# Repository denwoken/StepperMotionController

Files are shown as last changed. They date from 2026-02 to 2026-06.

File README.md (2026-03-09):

# StepperMotionController
StepperMotionController is a full hardware + firmware + software stack for controlling multiple stepper motors over RS-485 (Modbus RTU). You configure the required motion parameters, set a target position, and the controller computes and executes the motion trajectory and speed profile based on current speed and acceleration limits.

This repo contains the STM32G0 firmware, the PCB design, and a Python SDK.

Planned: feedback sensor support for detecting missed steps, plus richer driver control via a shared UART connected to all TMC2209 drivers.

**Repository Layout**
- `firmware/` STM32G071 firmware (FreeRTOS) that exposes a Modbus RTU register map for motor control.
- `controller_sdk/python/` Python SDK built on `pyserial` with a high-level API and examples.
- `Altium/` PCB/schematic sources for the controller hardware.
- `DeviceRegisters.xlsx` Source-of-truth register map.
- `mbpool device registers.mbw` Modbus Poll workspace for register testing.
- `firmware/Core/DeviceRegisters/` Generated C register map used by firmware.
- `firmware/scripts/` Tools to generate register map files from the Excel table.
- `LegacyDeviceRegisters/` Older register map versions and outputs.
- `firmware/Doc/` MCU datasheet, reference manual, and FreeRTOS docs.
- `firmware.code-workspace` VS Code workspace for firmware development.
- `AltiumProjectGroup.DsnWrk` Altium project group workspace file.

**Quick Start (Python)**
1. Install dependencies:
   `python -m pip install -r controller_sdk/python/requirements.txt`
2. Run the example (edit port and baudrate as needed):
   `python controller_sdk/python/examples/basic_usage.py`

Minimal python usage:
```python
from stepper_controller import StepperController

with StepperController(port="COM9", baudrate=256000, slave_id=1) as ctrl:
    print(ctrl.read_device_id())
    motor = ctrl.motor(0)
    motor.enable(True)
    motor.set_max_velocity(128000)
    motor.move_relative(64000)
```

**Firmware Build**
1. Open `firmware.code-workspace` in VScode press F5 to build and start debugging session.

Notes:
- Modbus RTU is configured on `USART1` with RS-485 DE; the default baudrate is `256000`.
- The firmware expects the register map generated into `firmware/Core/DeviceRegisters/`.

**Register Map**
The register map starts in `DeviceRegisters.xlsx` and is used by both firmware and the Python SDK.

SDK compatibility:
- `controller_sdk/python/stepper_controller/device_registers.py` mirrors the firmware map.
- The SDK checks the map version on `open()` and raises `RegisterMapMismatchError` if it differs. You can disable this check with `StepperController(..., verify_map_version=False)`.

**Hardware**
Open the Altium project in `Altium/` to view schematics and PCB layout.

**License**
MIT. See `LICENSE`.

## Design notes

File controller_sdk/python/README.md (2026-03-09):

**Overview**
This folder contains a small Python module that talks to the controller over Modbus RTU and exposes high-level methods for every register defined in `Core/DeviceRegisters`.

**Install**
1. Optional: create and activate a virtual environment.
2. Install dependencies with `python -m pip install -r requirements.txt`.

**Example**
From this folder: `python examples\basic_usage.py` (update port and baudrate).
From repo root: `python controller_sdk\python\examples\basic_usage.py`.

**Notes**
- Motor index is 0..motor_count-1 by default. Use `motor(one_based=True)` if you prefer 1..N.
- 32-bit registers use low-word then high-word order (matches firmware mapping).
- The client accepts absolute Modbus addresses (40000+) and 0-based indices.
- On `open()` the client checks register map version and raises `RegisterMapMismatchError` on mismatch. You can disable via `StepperController(..., verify_map_version=False)`.

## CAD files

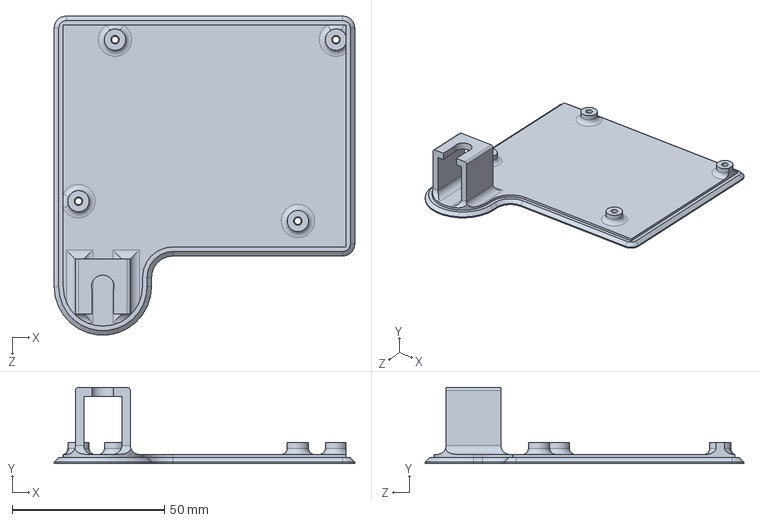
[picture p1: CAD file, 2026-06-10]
SolidWorks/PCB mounting plate.SLDPRT
98.7 x 25.0 x 104.7 mm

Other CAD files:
SolidWorks/PCB mounting plate.STL

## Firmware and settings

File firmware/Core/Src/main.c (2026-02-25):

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
/* Includes ------------------------------------------------------------------*/
#include "main.h"
#include "cmsis_os.h"
#include "crc.h"
#include "dma.h"
#include "i2c.h"
#include "spi.h"
#include "tim.h"
#include "usart.h"
#include "gpio.h"

/* USER CODE BEGIN Includes */
#include "FreeRTOS.h"
#include "semphr.h"
#include <stdio.h>

/* USER CODE END Includes */


void SystemClock_Config(void);
void MX_FREERTOS_Init(void);
/* USER CODE BEGIN PFP */


/*
static SemaphoreHandle_t ITM_mutex;
int _write(int file, char *ptr, int len)
{
  if(ITM_mutex == NULL)
    ITM_mutex = xSemaphoreCreateMutex();

    if (xSemaphoreTake(ITM_mutex, portMAX_DELAY) == pdTRUE)
    {
        for (int i = 0; i < len; i++){
            // Ждём пока USART готов к отправке
            while(!LL_USART_IsActiveFlag_TXE(USART1));
            LL_USART_TransmitData8(USART1, ptr[i]);
        }
        xSemaphoreGive(ITM_mutex);
    }
    return len;
}
*/
/* USER CODE END PFP */

/**
  * @brief  The application entry point.
  * @retval int
  */
int main(void)
{

  /* MCU Configuration--------------------------------------------------------*/

  /* Reset of all peripherals, Initializes the Flash interface and the Systick. */
  HAL_Init();

  /* Configure the system clock */
  SystemClock_Config();

  /* Initialize all configured peripherals */
  MX_GPIO_Init();
  MX_DMA_Init();
  MX_TIM6_Init();
  MX_TIM15_Init();
  MX_USART1_UART_Init();
  MX_TIM7_Init();
  MX_I2C1_Init();
  MX_I2C2_Init();
  MX_SPI1_Init();
  MX_TIM1_Init();
  MX_TIM2_Init();
  MX_TIM3_Init();
  MX_TIM16_Init();
  MX_TIM17_Init();
  MX_CRC_Init();
  /* Call init function for freertos objects (in cmsis_os2.c) */
  MX_FREERTOS_Init();

  /* Start scheduler */
  osKernelStart();

  /* We should never get here as control is now taken by the scheduler */

  /* Infinite loop */
  /* USER CODE BEGIN WHILE */
  while (1)
  {
    /* USER CODE END WHILE */

    /* USER CODE BEGIN 3 */
  }
  /* USER CODE END 3 */
}

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


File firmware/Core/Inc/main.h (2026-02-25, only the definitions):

#define PC11_Pin LL_GPIO_PIN_11
#define PC11_GPIO_Port GPIOC
#define PC12_Pin LL_GPIO_PIN_12
#define PC12_GPIO_Port GPIOC
#define PC13_Pin LL_GPIO_PIN_13
#define PC13_GPIO_Port GPIOC
#define PC14_Pin LL_GPIO_PIN_14
#define PC14_GPIO_Port GPIOC
#define PC15_Pin LL_GPIO_PIN_15
#define PC15_GPIO_Port GPIOC
#define DRV1_DIR_Pin LL_GPIO_PIN_0
#define DRV1_DIR_GPIO_Port GPIOC
#define DRV1_NEN_Pin LL_GPIO_PIN_2
#define DRV1_NEN_GPIO_Port GPIOC
#define DRV5_NEN_Pin LL_GPIO_PIN_3
#define DRV5_NEN_GPIO_Port GPIOC
#define DRV5_DIR_Pin LL_GPIO_PIN_1
#define DRV5_DIR_GPIO_Port GPIOA
#define DRV2_DIR_Pin LL_GPIO_PIN_5
#define DRV2_DIR_GPIO_Port GPIOA
#define DRV2_NEN_Pin LL_GPIO_PIN_7
#define DRV2_NEN_GPIO_Port GPIOA
#define DRV4_NEN_Pin LL_GPIO_PIN_15
#define DRV4_NEN_GPIO_Port GPIOB
#define DRV4_DIR_Pin LL_GPIO_PIN_9
#define DRV4_DIR_GPIO_Port GPIOA
#define ENC_BTN_Pin LL_GPIO_PIN_8
#define ENC_BTN_GPIO_Port GPIOD
#define DRV3_NEN_Pin LL_GPIO_PIN_0
#define DRV3_NEN_GPIO_Port GPIOD
#define DRV3_DIR_Pin LL_GPIO_PIN_2
#define DRV3_DIR_GPIO_Port GPIOD

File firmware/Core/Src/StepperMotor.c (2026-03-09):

#include "StepperMotor.h"
#include <assert.h>
#include <memory.h>
#include "config.h"


//declarations functions
static void StepperMotor_update(StepperMotor* self);
static void StepperMotor_init(StepperMotor* self, TIM_TypeDef *timer, GPIO_TypeDef *dir_port, uint16_t dir_pin,
	GPIO_TypeDef *en_port, uint16_t en_pin);
static void StepperMotor_setEnable(StepperMotor* self, bool enable);
static void StepperMotor_restartMotorTimer(StepperMotor* self);

static void StepperMotor_apply_control(StepperMotor* m, uint16_t value);
static void StepperMotor_apply_mode(StepperMotor* m, uint16_t value);
static void StepperMotor_apply_target_pos(StepperMotor* m, int32_t target);
static void StepperMotor_apply_move_rel(StepperMotor* m, int32_t move);



// link methods to class
static void StepperMotor_setAllmethods(StepperMotor* self){
	assert(self);
	self->update = StepperMotor_update;
	self->init = StepperMotor_init;
	self->setEnable = StepperMotor_setEnable;
	self->restartMotorTimer = StepperMotor_restartMotorTimer;

	self->apply_control = StepperMotor_apply_control;
	self->apply_mode = StepperMotor_apply_mode;
	self->apply_target_pos = StepperMotor_apply_target_pos;
	self->apply_move_rel = StepperMotor_apply_move_rel;

}


static inline int32_t _abs(int32_t x){ return x < 0 ? -x : x; }
static inline int32_t _min(int32_t a, int32_t b){ return a < b ? a : b; }
static inline int32_t _max(int32_t a, int32_t b){ return a > b ? a : b; }

const int s_max_velocity = 256000;


static void StepperMotor_apply_control(StepperMotor* m, uint16_t value)
{
	StepperMotorParameters* p = &m->parameters;
	
	// TODO: implement full control behavior (enable/disable, etc.)
	p->control.raw = value;

	m->setEnable(m, (bool)(value & MOTOR_CONTROL_EN_MASK));

	// Simple sketch: mirror enable bit into status and stop on disable.
	if ((value & MOTOR_CONTROL_EN_MASK)) {
		
		// p->remaining_steps = 0;
		// p->current_velocity = 0;
		// p->current_acceleration = 0;
		// p->move_pos_rel = 0;
		// p->target_pos = p->move_total_steps;
		// p->status.bits.running = 0u;
	}
	//p->status.bits.enabled = (value & MOTOR_CONTROL_EN_MASK) ? 1u : 0u;
}

static void StepperMotor_apply_mode(StepperMotor* m, uint16_t value)
{
	StepperMotorParameters* p = &m->parameters;
	// TODO: define mode semantics (position/velocity/step, etc.)
	p->mode = value;
}


#if defined(REG_ID_CMD)
static void StepperMotor_apply_cmd(StepperMotor* m, uint16_t value)
{
	const StepperMotorParameters* p = &m->parameters;
	// Write-only command register sketch.
	// TODO: replace with real command decoding.
	p->cmd = value;
	if (value & 0x0001u) {
		// CMD bit0: stop motion (placeholder action)
		p->remaining_steps = 0;
		p->current_velocity = 0;
		p->current_acceleration = 0;
		p->move_pos_rel = 0;
		p->target_pos = p->move_total_steps;
		p->status.bits.running = 0u;
	}
}
#endif

static void StepperMotor_apply_target_pos(StepperMotor* m, int32_t target)
{
	StepperMotorParameters* p = &m->parameters;
	p->target_pos = target;
	p->remaining_steps = p->target_pos - p->move_total_steps;
}

static void StepperMotor_apply_move_rel(StepperMotor* m, int32_t move)
{
	StepperMotorParameters* p = &m->parameters;
	p->remaining_steps += move;
	p->target_pos = p->move_total_steps + p->remaining_steps;
}








// methods
static void StepperMotor_update(StepperMotor* m){
	StepperMotorParameters* p = &m->parameters;
	//portENTER_CRITICAL();

	int8_t direction = (p->remaining_steps > 0) ? (1) : (-1);


	// Расчет дистанции торможения (правильная формула)
	// s = v² / (2 * a)
	int64_t brake_distance = 0;
	if (p->max_acceleration > 0) {
		brake_distance = ((int64_t)p->current_velocity * (int64_t)p->current_velocity);
		brake_distance /= (2 * p->max_acceleration);
	} else 
		brake_distance = INT64_MAX;
	int32_t abs_remaining = _abs(p->remaining_steps);

	

	
	//p->current_acceleration
	// ускорение за тик + аккумулируем значение если дробное
	int32_t total_acc = p->max_acceleration + m->accelerationAccumulated; 
	int32_t accel_per_tick =  total_acc / 1000;
	int32_t accel_sign = 0;
	m->accelerationAccumulated = total_acc % 1000;


	// Управление скоростью по трапециевидному профилю
	if ( abs_remaining <= brake_distance )
	{ // шагов нужно выполнить меньше чем нужно для тормаения
		//  ==> тормозим
		p->current_velocity = _max(0, p->current_velocity - accel_per_tick);
		accel_sign = -1;
	}
	else if (p->current_velocity < p->max_velocity ){
		// или если это не максимальная скорость  ==> ускоряемся
		p->current_velocity = _min(p->max_velocity, p->current_velocity + accel_per_tick);
		accel_sign = 1;
	}
	else if (p->current_velocity > p->max_velocity)
	{ // если vmax изменили в меньшую сторону ==> тормозим
		p->current_velocity = _max(p->max_velocity, p->current_velocity - accel_per_tick);
		accel_sign = -1;
	}


	// шаги/тик + аккумулируем значение если дробное
	p->current_acceleration = accel_sign * (int32_t)p->max_acceleration;

	int32_t total_vel = p->current_velocity + m->velocityAccumulated;
	int32_t vel_per_tick = total_vel / 1000;
	m->velocityAccumulated = total_vel % 1000;


	if (vel_per_tick != 0)
	{

		// НЕ допускать перепрыгивания через ноль:
		int32_t steps_to_move = vel_per_tick;
    if (steps_to_move > abs_remaining) steps_to_move = abs_remaining;

		if(steps_to_move > 256) steps_to_move = 256;

		//выбор направления двиения
		if(direction == 1){ 
			LL_GPIO_SetOutputPin(m->dir_port, m->dir_pin);
			p->remaining_steps -= steps_to_move;
			p->move_total_steps += steps_to_move;
		} else {
			LL_GPIO_ResetOutputPin(m->dir_port, m->dir_pin);
			p->remaining_steps += steps_to_move;
			p->move_total_steps -= steps_to_move;
		}
		if(p->remaining_steps == 0 ){
			//LL_GPIO_ResetOutputPin(m->dir_port, m->dir_pin);// дебаг
			p->current_velocity = 0;
			p->current_acceleration = 0;
			m->velocityAccumulated = 0;
			m->accelerationAccumulated = 0;
		}


		//LL_TIM_DisableCounter(m->timer);
		static const uint32_t timer_clk = 64000; // кГц
		LL_TIM_SetPrescaler(m->timer, ( timer_clk/(steps_to_move*2) ) );//- 1
    LL_TIM_SetRepetitionCounter(m->timer, steps_to_move - 1);//
		
		//LL_TIM_GenerateEvent_UPDATE(m->timer);
		//LL_TIM_EnableCounter(m->timer);
		m->pendingTimerRestart = true;

	} else m->pendingTimerRestart = false;

	if (vel_per_tick == 0 && p->remaining_steps == 0) {
		p->current_velocity = 0;
		p->current_acceleration = 0;
		m->velocityAccumulated = 0;
		m->accelerationAccumulated = 0;
	}

	p->target_pos = p->move_total_steps + p->remaining_steps;
	const uint16_t is_running = (p->remaining_steps != 0) ? 1u : 0u;
	p->status.bits.running = is_running;
	p->status.bits.enabled = is_running;

	//portEXIT_CRITICAL();
}


static void StepperMotor_setEnable(StepperMotor* self, bool enable){
	assert(self);
	assert(self->en_port);
	assert(self->en_pin != 0u);

	if(enable){
		// NEN is active-low: 0 = enabled, 1 = disabled.
		LL_GPIO_ResetOutputPin(self->en_port, self->en_pin);
	} else {
		LL_GPIO_SetOutputPin(self->en_port, self->en_pin);
	}
}
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

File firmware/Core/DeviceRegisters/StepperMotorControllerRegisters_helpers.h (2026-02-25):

#pragma once
#include "StepperMotorControllerRegisters_map.h"

// FW_VERSION helpers: high byte = register map version, low byte = firmware version (major*10+minor).
#define REG_FW_VERSION_PACK(map_ver, fw_ver) \
	((uint16_t)((((uint16_t)(map_ver) & 0xFFu) << 8) | ((uint16_t)(fw_ver) & 0xFFu)))
#define REG_FW_VERSION_MAP(ver_u16) ((uint8_t)(((uint16_t)(ver_u16) >> 8) & 0xFFu))
#define REG_FW_VERSION_SW(ver_u16)  ((uint8_t)((uint16_t)(ver_u16) & 0xFFu))
#define REG_FW_VERSION_MAJOR(ver_u16) ((uint8_t)(REG_FW_VERSION_SW(ver_u16) / 10u))
#define REG_FW_VERSION_MINOR(ver_u16) ((uint8_t)(REG_FW_VERSION_SW(ver_u16) % 10u))

// Helper macros for register addresses/sizes.
// - REG_SIZE_* is in 16-bit Modbus words (1 for 16-bit, 2 for 32-bit).
// - Motors in helper macros REG_Mx_* are 1-based in the name, but internally use 0-based indexing.

#define REG_BASE_DEVICE_ID ((uint16_t)40000)
#define REG_SIZE_DEVICE_ID ((uint8_t)1)
#define REG_PER_MOTOR_DEVICE_ID ((uint8_t)0)
#define REG_BASE_FW_VERSION ((uint16_t)40001)
#define REG_SIZE_FW_VERSION ((uint8_t)1)
#define REG_PER_MOTOR_FW_VERSION ((uint8_t)0)
#define REG_BASE_MOTOR_COUNT ((uint16_t)40002)
#define REG_SIZE_MOTOR_COUNT ((uint8_t)1)
#define REG_PER_MOTOR_MOTOR_COUNT ((uint8_t)0)
#define REG_BASE_CONTROL ((uint16_t)40008)
#define REG_SIZE_CONTROL ((uint8_t)1)
#define REG_PER_MOTOR_CONTROL ((uint8_t)1)
#define REG_BASE_STATUS ((uint16_t)40013)
#define REG_SIZE_STATUS ((uint8_t)1)
#define REG_PER_MOTOR_STATUS ((uint8_t)1)
#define REG_BASE_ERROR_CODE ((uint16_t)40018)
#define REG_SIZE_ERROR_CODE ((uint8_t)1)
#define REG_PER_MOTOR_ERROR_CODE ((uint8_t)1)
#define REG_BASE_MODE ((uint16_t)40023)
#define REG_SIZE_MODE ((uint8_t)1)
#define REG_PER_MOTOR_MODE ((uint8_t)1)
#define REG_BASE_CURRENT_POS_32 ((uint16_t)40032)
#define REG_SIZE_CURRENT_POS_32 ((uint8_t)2)
#define REG_PER_MOTOR_CURRENT_POS_32 ((uint8_t)1)
#define REG_BASE_CURRENT_VELOCITY_32 ((uint16_t)40042)
#define REG_SIZE_CURRENT_VELOCITY_32 ((uint8_t)2)
#define REG_PER_MOTOR_CURRENT_VELOCITY_32 ((uint8_t)1)
#define REG_BASE_CURRENT_ACCEL_32 ((uint16_t)40052)
#define REG_SIZE_CURRENT_ACCEL_32 ((uint8_t)2)
#define REG_PER_MOTOR_CURRENT_ACCEL_32 ((uint8_t)1)
#define REG_BASE_TARGET_POS_32 ((uint16_t)40062)
#define REG_SIZE_TARGET_POS_32 ((uint8_t)2)
#define REG_PER_MOTOR_TARGET_POS_32 ((uint8_t)1)
#define REG_BASE_MOVE_POS_REL_32 ((uint16_t)40072)
#define REG_SIZE_MOVE_POS_REL_32 ((uint8_t)2)
#define REG_PER_MOTOR_MOVE_POS_REL_32 ((uint8_t)1)
#define REG_BASE_MAX_VELOCITY_32 ((uint16_t)40082)
#define REG_SIZE_MAX_VELOCITY_32 ((uint8_t)2)
#define REG_PER_MOTOR_MAX_VELOCITY_32 ((uint8_t)1)
#define REG_BASE_MAX_ACCEL_32 ((uint16_t)40092)
#define REG_SIZE_MAX_ACCEL_32 ((uint8_t)2)
#define REG_PER_MOTOR_MAX_ACCEL_32 ((uint8_t)1)

#define REG_M1_CONTROL_ADDR (uint16_t)(REG_BASE_CONTROL + (uint16_t)(0) * (uint16_t)REG_SIZE_CONTROL)
#define REG_M1_CONTROL_OFFSET (uint16_t)((uint16_t)(0) * (uint16_t)REG_SIZE_CONTROL)
#define REG_M2_CONTROL_ADDR (uint16_t)(REG_BASE_CONTROL + (uint16_t)(1) * (uint16_t)REG_SIZE_CONTROL)
#define REG_M2_CONTROL_OFFSET (uint16_t)((uint16_t)(1) * (uint16_t)REG_SIZE_CONTROL)
#define REG_M3_CONTROL_ADDR (uint16_t)(REG_BASE_CONTROL + (uint16_t)(2) * (uint16_t)REG_SIZE_CONTROL)
#define REG_M3_CONTROL_OFFSET (uint16_t)((uint16_t)(2) * (uint16_t)REG_SIZE_CONTROL)
#define REG_M4_CONTROL_ADDR (uint16_t)(REG_BASE_CONTROL + (uint16_t)(3) * (uint16_t)REG_SIZE_CONTROL)
#define REG_M4_CONTROL_OFFSET (uint16_t)((uint16_t)(3) * (uint16_t)REG_SIZE_CONTROL)
#define REG_M5_CONTROL_ADDR (uint16_t)(REG_BASE_CONTROL + (uint16_t)(4) * (uint16_t)REG_SIZE_CONTROL)
#define REG_M5_CONTROL_OFFSET (uint16_t)((uint16_t)(4) * (uint16_t)REG_SIZE_CONTROL)

#define REG_M1_STATUS_ADDR (uint16_t)(REG_BASE_STATUS + (uint16_t)(0) * (uint16_t)REG_SIZE_STATUS)
#define REG_M1_STATUS_OFFSET (uint16_t)((uint16_t)(0) * (uint16_t)REG_SIZE_STATUS)
#define REG_M2_STATUS_ADDR (uint16_t)(REG_BASE_STATUS + (uint16_t)(1) * (uint16_t)REG_SIZE_STATUS)
#define REG_M2_STATUS_OFFSET (uint16_t)((uint16_t)(1) * (uint16_t)REG_SIZE_STATUS)
#define REG_M3_STATUS_ADDR (uint16_t)(REG_BASE_STATUS + (uint16_t)(2) * (uint16_t)REG_SIZE_STATUS)
#define REG_M3_STATUS_OFFSET (uint16_t)((uint16_t)(2) * (uint16_t)REG_SIZE_STATUS)
#define REG_M4_STATUS_ADDR (uint16_t)(REG_BASE_STATUS + (uint16_t)(3) * (uint16_t)REG_SIZE_STATUS)
#define REG_M4_STATUS_OFFSET (uint16_t)((uint16_t)(3) * (uint16_t)REG_SIZE_STATUS)
#define REG_M5_STATUS_ADDR (uint16_t)(REG_BASE_STATUS + (uint16_t)(4) * (uint16_t)REG_SIZE_STATUS)
#define REG_M5_STATUS_OFFSET (uint16_t)((uint16_t)(4) * (uint16_t)REG_SIZE_STATUS)

#define REG_M1_ERROR_CODE_ADDR (uint16_t)(REG_BASE_ERROR_CODE + (uint16_t)(0) * (uint16_t)REG_SIZE_ERROR_CODE)
#define REG_M1_ERROR_CODE_OFFSET (uint16_t)((uint16_t)(0) * (uint16_t)REG_SIZE_ERROR_CODE)
#define REG_M2_ERROR_CODE_ADDR (uint16_t)(REG_BASE_ERROR_CODE + (uint16_t)(1) * (uint16_t)REG_SIZE_ERROR_CODE)
#define REG_M2_ERROR_CODE_OFFSET (uint16_t)((uint16_t)(1) * (uint16_t)REG_SIZE_ERROR_CODE)
#define REG_M3_ERROR_CODE_ADDR (uint16_t)(REG_BASE_ERROR_CODE + (uint16_t)(2) * (uint16_t)REG_SIZE_ERROR_CODE)
#define REG_M3_ERROR_CODE_OFFSET (uint16_t)((uint16_t)(2) * (uint16_t)REG_SIZE_ERROR_CODE)
#define REG_M4_ERROR_CODE_ADDR (uint16_t)(REG_BASE_ERROR_CODE + (uint16_t)(3) * (uint16_t)REG_SIZE_ERROR_CODE)
#define REG_M4_ERROR_CODE_OFFSET (uint16_t)((uint16_t)(3) * (uint16_t)REG_SIZE_ERROR_CODE)
#define REG_M5_ERROR_CODE_ADDR (uint16_t)(REG_BASE_ERROR_CODE + (uint16_t)(4) * (uint16_t)REG_SIZE_ERROR_CODE)
#define REG_M5_ERROR_CODE_OFFSET (uint16_t)((uint16_t)(4) * (uint16_t)REG_SIZE_ERROR_CODE)

#define REG_M1_MODE_ADDR (uint16_t)(REG_BASE_MODE + (uint16_t)(0) * (uint16_t)REG_SIZE_MODE)
#define REG_M1_MODE_OFFSET (uint16_t)((uint16_t)(0) * (uint16_t)REG_SIZE_MODE)
#define REG_M2_MODE_ADDR (uint16_t)(REG_BASE_MODE + (uint16_t)(1) * (uint16_t)REG_SIZE_MODE)
#define REG_M2_MODE_OFFSET (uint16_t)((uint16_t)(1) * (uint16_t)REG_SIZE_MODE)
#define REG_M3_MODE_ADDR (uint16_t)(REG_BASE_MODE + (uint16_t)(2) * (uint16_t)REG_SIZE_MODE)
#define REG_M3_MODE_OFFSET (uint16_t)((uint16_t)(2) * (uint16_t)REG_SIZE_MODE)
#define REG_M4_MODE_ADDR (uint16_t)(REG_BASE_MODE + (uint16_t)(3) * (uint16_t)REG_SIZE_MODE)
#define REG_M4_MODE_OFFSET (uint16_t)((uint16_t)(3) * (uint16_t)REG_SIZE_MODE)
#define REG_M5_MODE_ADDR (uint16_t)(REG_BASE_MODE + (uint16_t)(4) * (uint16_t)REG_SIZE_MODE)
#define REG_M5_MODE_OFFSET (uint16_t)((uint16_t)(4) * (uint16_t)REG_SIZE_MODE)
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

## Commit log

2026-02-12 DEV: import altium files to project. Draft of the board for testing
    [Sheet.SchDoc, Sheet1.SchDoc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]
2026-02-14 DEV: developed registers for device
    [регистры modbus.xlsx]
2026-02-14 DEV: modify registers
    [modbus registers.xlsx, регистры modbus.xlsx]
2026-02-15 DEV: Implemented draft initialization for I2C, SPI, and TIM peripherals. Fixed timing parameters for RS-485 hardware control.
    [ModbusSlaveRTU.c, app_freertos.c, main.c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]
2026-02-16 DEV: added device registers for first motor fin "modbusPool" Application & creating workspace, also some fixes in code.
    [StepperMotionControl.ioc]
2026-02-16 DEV: add lfs filter
2026-02-16 DEV: moved motor parameters into StepperMotorParameters struct; fixed TIM15 config bug
    [StepperMotionControl.ioc, StepperMotor.c, app_freertos.c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]
2026-02-16 DEV: implemented simplified python script for generting DeviceRegisters.h/.c files from excel registers tabel
    [DeviceRegisters.xlsx, modbus registers.xlsx]
2026-02-22 tmp garbage
    [DeviceRegisters.xlsx]
2026-02-23 DEV: barely working modbus communication. in progress of removing 16bit reg copy
    [DeviceRegisters.xlsx]
2026-02-23 DEV: implementation of 32bit motion registers instead of 16bit. now you can move single StepperMotor via modbus registers
2026-02-23 DEV: fix some bugs. now its working
    [DeviceRegistersMapper.c, StepperMotionControl.ioc, StepperMotor.c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]
2026-02-25 DEV: fix some jitter bugs & sync motors. added crc base init.
    [StepperMotionControl.ioc, StepperMotor.c, StepperMotorController.c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]
2026-02-25 DEV: implemented macros hooks in StepperMotorController, automatic determination fw version from git tag
2026-02-25 DEV: renaming DeviceRegisters files
2026-03-09 something weird with altium schematic....
    [Sheet.SchDoc]
2026-06-09 rectified mistake in U1 commment; fixed mistake in sch and pcb
    [PCB1.PcbDoc, Sheet.SchDoc, Sheet1.SchDoc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]
2026-06-09 add PCB mounting plate model
    [PCB mounting plate.SLDPRT, PCB mounting plate.STL]
2026-06-10 Add PCB and assembly Draftsman documents and also GOST BOM
    [Bill of Materials-StepperMotionController.xls, PCB mounting plate.SLDPRT, PCB mounting plate.STL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]
2026-06-10 Move Altium files to Git LFS
    [WireFeeder.PcbDoc, WireFeeder.PcbLib, WireFeeder.PrjPcb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]

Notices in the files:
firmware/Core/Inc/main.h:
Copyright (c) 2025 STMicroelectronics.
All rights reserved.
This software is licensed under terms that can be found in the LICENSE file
